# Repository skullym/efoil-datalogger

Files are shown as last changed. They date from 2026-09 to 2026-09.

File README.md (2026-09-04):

# efoil-datalogger
VESC based efoil data logger design by Mike Schulster
_____________________________________________________________________________________

DATA LOGGER DESIGN SPECS :
_________________________________________
Microcontroller : ESP32 Dev Module 38-pin

Storage : MicroSD module and 8GB card

GNSS : SAM-M10Q GNSS antenna module receiver from GNSS.store

Power : 5V from Vesc

________________________________
COMMS ARCHITECTURE :
_______________________________
Throttle : PPM from VESC  

VESC telemetry : UART 1 (COMM port)

GNSS : ESP32 UART 2

SD card : SPI

_______________________________
WIRING:
_______________________________
VESC UART1 TX  →  ESP32 GPIO16

VESC UART1 RX  ←  ESP32 GPIO17

GPS TX         →  ESP32 GPIO16  [use UART2]

GPS RX         ←  ESP32 GPIO17

SD CS/MOSI/MISO/CLK → GPIO 15/23/19/18

_______________________________________
OUTPUT FORMAT :
_______________________________________
Native VESC Tool CSV format

Exact header row from real VESC logs

One file per ride, named by GPS date/time

~5 Hz sample rate

___________________________________________
KEY LOGGED CHANNELS :
___________________________________________
VESC: voltage, motor current, input current, ERPM, duty cycle, watt-hours, FET temp, motor temp (via NTC) GPS: lat, lon, ground speed, altitude, time

___________________________________________________
RIDE DETECTION:
___________________________________________________
Auto-start: GPS speed >1 m/s or ERPM above threshold

Auto-stop: 30s idle timeout

Clean file close on stop

____________________________________________________
ANTENNA INSTALLATION :
____________________________________________________
Mounted flat, ceramic face up,

Small copper/aluminium ground plane underneath

15–20 cm minimum from ESC and battery cables if possible

Cable routed away from power wiring

_____________________________________________________________________
DATA LOGGER WIFI INTERFACE :
_____________________________________________________________________
SSID : eFoilLogger

Password : efoillogger

Can be changed in code lines 40 and 41

__________________________________________________________
FUNCTIONALITY :
__________________________________________________________
The logger has auto start-stop functionality built in - 

AUTO START : GNSS speed > 1.0 m/s for 3 seconds OR VESC data is recent AND abs(ERPM) > 300 for 3 seconds (can be changed on lines 63-64)

AUTO STOP :  no recent VESC data OR abs(ERPM) < 200 AND abs(input current) < 1.0 A OR GNSS speed < 0.7 m/s for at least 54 of the last 60 one-second samples (can be changed on lines 65-71) 

Also the logging can be MANUALLY started and stopped from the web interface.

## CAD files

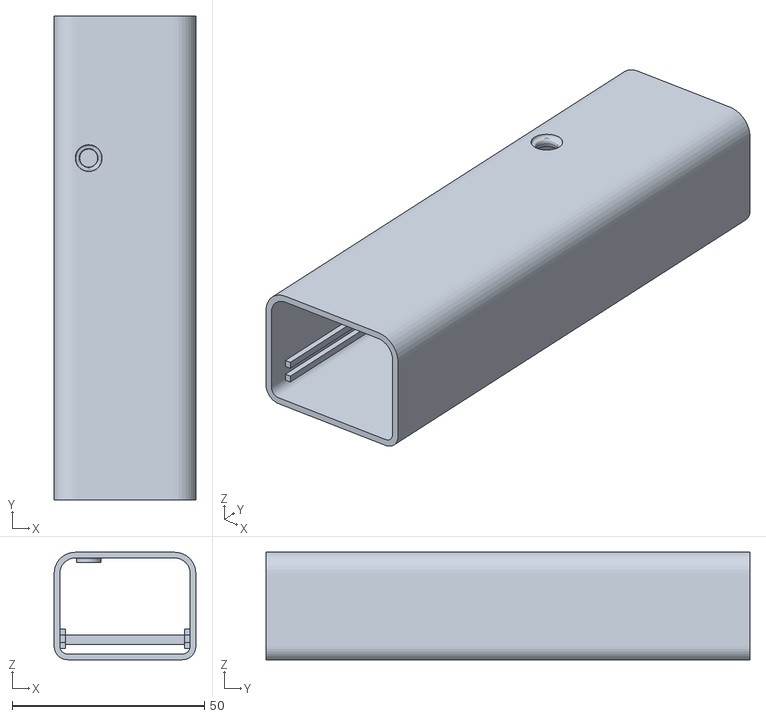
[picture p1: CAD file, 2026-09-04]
20260824 Data logger sleeve v2.0.stl
36.9 x 126.0 x 28.0

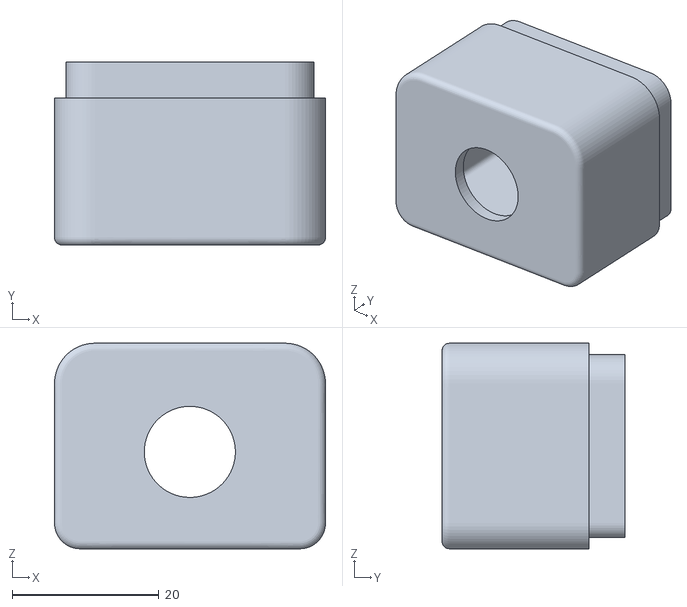
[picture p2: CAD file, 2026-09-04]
20260824 Cap hole V2.stl
36.9 x 24.9 x 28.0

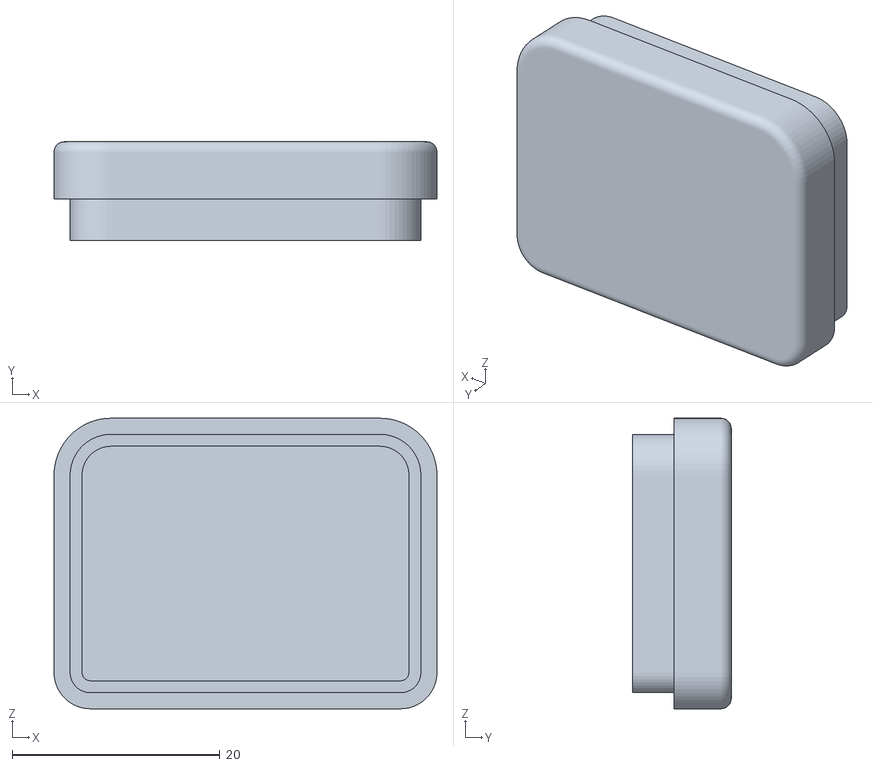
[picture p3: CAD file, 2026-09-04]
20260824 Cap blind V2.stl
36.9 x 9.50 x 28.0

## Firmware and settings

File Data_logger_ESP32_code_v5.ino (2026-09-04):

#include <TinyGPSPlus.h>
#include <SPI.h>
#include <SD.h>
#include <WiFi.h>
#include <WebServer.h>
#include <DNSServer.h>

// ELT0169 TX connects to GPIO25 (ESP32 RX).
// ELT0169 RX connects to GPIO26 (ESP32 TX).
constexpr int GPS_RX_PIN = 25;
constexpr int GPS_TX_PIN = 26;
constexpr uint32_t GPS_BAUD = 9600;

// VESC COMM UART.
// VESC TX connects to GPIO16 (ESP32 RX).
// VESC RX connects to GPIO17 (ESP32 TX).
constexpr int VESC_RX_PIN = 16;
constexpr int VESC_TX_PIN = 17;
constexpr uint32_t VESC_BAUD = 115200;
constexpr uint8_t COMM_GET_VALUES = 4;

// microSD module using the ESP32 VSPI pins.
constexpr int SD_CS_PIN = 5;
constexpr int SD_SCK_PIN = 18;
constexpr int SD_MISO_PIN = 19;
constexpr int SD_MOSI_PIN = 23;
constexpr uint32_t SD_SPI_FREQ = 1000000;
const char VESC_CSV_HEADER[] =
    "ms_today;input_voltage;temp_mos_max;temp_mos_1;temp_mos_2;temp_mos_3;"
    "temp_motor;current_motor;current_in;d_axis_current;q_axis_current;erpm;"
    "duty_cycle;amp_hours_used;amp_hours_charged;watt_hours_used;"
    "watt_hours_charged;tachometer;tachometer_abs;encoder_position;fault_code;"
    "vesc_id;d_axis_voltage;q_axis_voltage;ms_today_setup;amp_hours_setup;"
    "amp_hours_charged_setup;watt_hours_setup;watt_hours_charged_setup;"
    "battery_level;battery_wh_tot;current_in_setup;current_motor_setup;"
    "speed_meters_per_sec;tacho_meters;tacho_abs_meters;num_vescs;"
    "ms_today_imu;roll;pitch;yaw;accX;accY;accZ;gyroX;gyroY;gyroZ;"
    "gnss_posTime;gnss_lat;gnss_lon;gnss_alt;gnss_gVel;gnss_vVel;"
    "gnss_hAcc;gnss_vAcc;";
const char WIFI_SSID[] = "eFoilLogger";
const char WIFI_PASSWORD[] = "efoillogger";
constexpr byte DNS_PORT = 53;

// External status LED on GPIO27.
constexpr int LED_PIN = 27;
constexpr bool LED_ON = HIGH;
constexpr bool LED_OFF = LOW;

constexpr uint32_t REPORT_INTERVAL_MS = 1000;
constexpr bool SERIAL_LIVE_STATUS = false;
constexpr uint32_t SD_RETRY_INTERVAL_MS = 5000;
constexpr uint32_t VESC_POLL_INTERVAL_MS = 100;
constexpr uint32_t LOG_INTERVAL_MS = 200;
constexpr uint32_t LOG_FLUSH_INTERVAL_MS = 1000;
constexpr uint32_t LOG_CHECKPOINT_INTERVAL_MS = 30000;
constexpr bool LOG_FLUSH_EVERY_ROW = true;
constexpr uint32_t VESC_MAX_AGE_MS = 1000;
constexpr uint32_t FIX_MAX_AGE_MS = 2000;
constexpr uint32_t LED_GNSS_WAIT_BLINK_INTERVAL_MS = 250;
constexpr uint32_t LED_RECORD_PULSE_INTERVAL_MS = 2000;
constexpr uint32_t LED_RECORD_PULSE_OFF_MS = 120;
constexpr float START_SPEED_MPS = 1.0f;
constexpr float START_ERPM_ABS = 300.0f;
constexpr uint32_t START_CONFIRM_MS = 3000;
constexpr float STOP_SPEED_MPS = 0.7f;
constexpr float STOP_ERPM_ABS = 200.0f;
constexpr float STOP_INPUT_CURRENT_A = 1.0f;
constexpr uint32_t STOP_SPEED_SAMPLE_INTERVAL_MS = 1000;
constexpr uint8_t STOP_SPEED_WINDOW_SAMPLES = 60;
constexpr uint8_t STOP_SPEED_LOW_SAMPLES_REQUIRED = 54;
constexpr bool AUTO_STOP_ENABLED = true;
constexpr float DEFAULT_GNSS_HACC_M = 3.0f;
constexpr float DEFAULT_GNSS_VACC_M = 5.0f;
constexpr size_t MAX_WEB_FILES = 40;
constexpr uint8_t VESC_CSV_SEMICOLONS = 55;
constexpr uint8_t WEB_REFRESH_SECONDS = 5;
constexpr int32_t LOG_TIME_OFFSET_SECONDS = 2 * 3600;
constexpr uint32_t MS_PER_DAY = 86400000UL;

enum LoggerState {
  STATE_IDLE,
  STATE_RECORDING
};

TinyGPSPlus gps;
HardwareSerial gpsSerial(1);
HardwareSerial vescSerial(2);
WebServer *server = nullptr;
DNSServer dnsServer;

uint32_t lastReportMs = 0;
uint32_t lastSdRetryMs = 0;
uint32_t lastVescPollMs = 0;
uint32_t lastVescDataMs = 0;
uint32_t lastLogMs = 0;
uint32_t lastLogFlushMs = 0;
uint32_t lastLogCheckpointMs = 0;
uint32_t lastLedToggleMs = 0;
uint32_t logStartMillis = 0;
uint32_t logStartMsToday = 0;
uint32_t recordingStartedMillis = 0;
uint32_t lastRecordingDurationMs = 0;
uint32_t skippedBadRows = 0;
uint32_t loggedRows = 0;
uint32_t lastKnownLogSize = 0;
bool ledState = false;
bool sdReady = false;
bool logReady = false;
bool gnss5HzConfigured = false;
bool manualStartPending = false;
LoggerState loggerState = STATE_IDLE;
char logFileName[32] = "";
char lastStopReason[40] = "none";
File logFile;
uint32_t speedStartSinceMs = 0;
uint32_t erpmStartSinceMs = 0;
uint32_t lastStopSpeedSampleMs = 0;
uint8_t stopSpeedSampleIndex = 0;
uint8_t stopSpeedSampleCount = 0;
uint8_t stopSpeedLowSampleCount = 0;
bool stopSpeedLowSamples[STOP_SPEED_WINDOW_SAMPLES] = {false};
float vescTempMos = 0.0f;
float vescTempMotor = 0.0f;
float vescMotorCurrent = 0.0f;
float vescInputCurrent = 0.0f;
float vescDuty = 0.0f;
float vescRpm = 0.0f;
float vescVoltage = 0.0f;
float vescAmpHours = 0.0f;
float vescAmpHoursCharged = 0.0f;
float vescWattHours = 0.0f;
float vescWattHoursCharged = 0.0f;
int32_t vescTachometer = 0;
int32_t vescTachometerAbs = 0;
uint8_t vescFaultCode = 0;

void printTwoDigits(uint8_t value) {
  if (value < 10) {
    Serial.print('0');
  }
  Serial.print(value);
}

void printStatus() {
  const bool hasFix =
      gps.location.isValid() && gps.location.age() <= FIX_MAX_AGE_MS;

  Serial.print(F("GNSS fix="));
  Serial.print(hasFix ? F("YES") : F("NO"));

  Serial.print(F(", state="));
  Serial.print(loggerState == STATE_RECORDING ? F("RECORDING") : F("IDLE"));
  if (manualStartPending) {
    Serial.print(F("(manual start pending)"));
  }

  Serial.print(F(", sats="));
  if (gps.satellites.isValid()) {
    Serial.print(gps.satellites.value());
  } else {
    Serial.print(F("?"));
  }

  Serial.print(F(", hdop="));
  if (gps.hdop.isValid()) {
    Serial.print(gps.hdop.hdop(), 1);
  } else {
    Serial.print(F("?"));
  }

  Serial.print(F(", pos="));
  if (gps.location.isValid()) {
    Serial.print(gps.location.lat(), 7);
    Serial.print(F("/"));
    Serial.print(gps.location.lng(), 7);
  } else {
    Serial.print(F("waiting"));
  }

  Serial.print(F(", speed="));
  if (gps.speed.isValid()) {
    Serial.print(gps.speed.kmph(), 2);
    Serial.print(F("km/h"));
  } else {
    Serial.print(F("?"));
  }

  Serial.print(F(", local="));
  if (gps.date.isValid() && gps.time.isValid()) {
    uint16_t localYear;
    uint8_t localMonth;
    uint8_t localDay;
    uint8_t localHour;
    uint8_t localMinute;
    uint8_t localSecond;
    localGpsDateTime(localYear, localMonth, localDay,
                     localHour, localMinute, localSecond);

    Serial.print(localYear);
    Serial.print('-');
    printTwoDigits(localMonth);
    Serial.print('-');
    printTwoDigits(localDay);
    Serial.print(' ');
    printTwoDigits(localHour);
    Serial.print(':');
    printTwoDigits(localMinute);
    Serial.print(':');
    printTwoDigits(localSecond);
  } else {
    Serial.print(F("waiting"));
  }

  Serial.print(F(", nmea="));
  Serial.print(gps.charsProcessed());

  Serial.print(F(", VESC="));
  if (millis() - lastVescDataMs <= VESC_MAX_AGE_MS) {
    Serial.print(F("duty="));
    Serial.print(vescDuty * 100.0f, 1);
    Serial.print(F("% erpm="));
    Serial.print(vescRpm, 0);
    Serial.print(F(" motorA="));
    Serial.print(vescMotorCurrent, 1);
    Serial.print(F(" inputA="));
    Serial.print(vescInputCurrent, 1);
    Serial.print(F(" volts="));
    Serial.print(vescVoltage, 1);
  } else {
    Serial.print(F("waiting"));
  }

  Serial.print(F(", SD="));
  Serial.print(sdReady ? F("OK") : F("not ready"));

  Serial.print(F(", log="));
  if (logReady) {
    Serial.print(logFileName);
    Serial.print(F(", rows="));
    Serial.print(loggedRows);
    Serial.print(F(", size="));
    Serial.println(lastKnownLogSize);
  } else if (loggerState == STATE_IDLE && !manualStartPending) {
    Serial.println(F("not recording"));
  } else if (!sdReady) {
    Serial.println(F("waiting for SD"));
  } else if (!gpsDateTimeIsSane()) {
    Serial.println(F("waiting for valid GNSS date/time"));
  } else if (!gpsLocationIsUsable()) {
    Serial.println(F("waiting for usable GNSS position"));
  } else {
    Serial.println(F("ready"));
  }
}

uint16_t crc16(const uint8_t *data, uint16_t len) {
  uint16_t crc = 0;

  for (uint16_t i = 0; i < len; i++) {
    crc ^= static_cast<uint16_t>(data[i]) << 8;

    for (uint8_t bit = 0; bit < 8; bit++) {
      if (crc & 0x8000) {
        crc = (crc << 1) ^ 0x1021;
      } else {
        crc <<= 1;
      }
    }
  }

  return crc;
}

int16_t readInt16(const uint8_t *buffer, uint16_t &index) {
  uint16_t raw = (static_cast<uint16_t>(buffer[index]) << 8) |
                 static_cast<uint16_t>(buffer[index + 1]);
  index += 2;
  return static_cast<int16_t>(raw);
}

int32_t readInt32(const uint8_t *buffer, uint16_t &index) {
  uint32_t raw = (static_cast<uint32_t>(buffer[index]) << 24) |
                 (static_cast<uint32_t>(buffer[index + 1]) << 16) |
                 (static_cast<uint32_t>(buffer[index + 2]) << 8) |
                 static_cast<uint32_t>(buffer[index + 3]);
  index += 4;
  return static_cast<int32_t>(raw);
}

void sendVescGetValues() {
  const uint8_t payload[] = {COMM_GET_VALUES};
  const uint16_t crc = crc16(payload, sizeof(payload));

  vescSerial.write(2);
  vescSerial.write(sizeof(payload));
  vescSerial.write(payload, sizeof(payload));
  vescSerial.write(static_cast<uint8_t>(crc >> 8));
  vescSerial.write(static_cast<uint8_t>(crc & 0xFF));
  vescSerial.write(3);
}

void parseVescPayload(const uint8_t *payload, uint16_t len) {
  if (len < 1 || payload[0] != COMM_GET_VALUES) {
    return;
  }

  // COMM_GET_VALUES response layout starts with temperatures/currents, then
  // duty cycle and ERPM. Skip fields we are not showing in this test sketch.
  uint16_t index = 1;
  if (len < 55) {
    return;
  }

  vescTempMos = readInt16(payload, index) / 10.0f;
  vescTempMotor = readInt16(payload, index) / 10.0f;
  vescMotorCurrent = readInt32(payload, index) / 100.0f;
  vescInputCurrent = readInt32(payload, index) / 100.0f;
  readInt32(payload, index);                 // id current / 100
  readInt32(payload, index);                 // iq current / 100
  vescDuty = readInt16(payload, index) / 1000.0f;
  vescRpm = readInt32(payload, index);
  vescVoltage = readInt16(payload, index) / 10.0f;
  vescAmpHours = readInt32(payload, index) / 10000.0f;
  vescAmpHoursCharged = readInt32(payload, index) / 10000.0f;
  vescWattHours = readInt32(payload, index) / 10000.0f;
  vescWattHoursCharged = readInt32(payload, index) / 10000.0f;
  vescTachometer = readInt32(payload, index);
  vescTachometerAbs = readInt32(payload, index);
  vescFaultCode = payload[index];
  lastVescDataMs = millis();
}

void pollVesc(uint32_t now) {
  if (now - lastVescPollMs < VESC_POLL_INTERVAL_MS) {
    return;
  }

  lastVescPollMs = now;
  sendVescGetValues();
}

void readVesc() {
  static uint8_t packet[256];
  static uint16_t index = 0;
  static uint16_t payloadLen = 0;
  static uint8_t crcHigh = 0;
  static uint8_t crcLow = 0;
  static uint8_t state = 0;

  while (vescSerial.available() > 0) {
    const uint8_t value = vescSerial.read();

    switch (state) {
      case 0:
        if (value == 2) {
          state = 1;
          index = 0;
          payloadLen = 0;
        }
        break;

      case 1:
        payloadLen = value;
        if (payloadLen == 0 || payloadLen > sizeof(packet)) {
          state = 0;
        } else {
          state = 2;
        }
        break;

      case 2:
        packet[index++] = value;
        if (index >= payloadLen) {
          state = 3;
        }
        break;

      case 3: {
        crcHigh = value;
        state = 4;
        break;
      }

      case 4:
        crcLow = value;
        state = 5;
        break;

      case 5: {
        const uint8_t endByte = value;
        const uint16_t receivedCrc =
            (static_cast<uint16_t>(crcHigh) << 8) | crcLow;

        if (endByte == 3 && receivedCrc == crc16(packet, payloadLen)) {
          parseVescPayload(packet, payloadLen);
        }

        state = 0;
        break;
      }
    }
  }
}

void testSdCard() {
  Serial.println();
  Serial.println(F("--- SD card test ---"));
  Serial.println(F("Pins: CS=5, SCK=18, MISO=19, MOSI=23"));

  SPI.begin(SD_SCK_PIN, SD_MISO_PIN, SD_MOSI_PIN, SD_CS_PIN);

  if (!SD.begin(SD_CS_PIN, SPI, SD_SPI_FREQ)) {
    Serial.println(F("SD init failed. Check wiring, power, card format and CS pin."));
    sdReady = false;
    return;
  }

  sdReady = true;
  Serial.println(F("SD init OK"));

  uint64_t cardSizeMb = SD.cardSize() / (1024ULL * 1024ULL);
  Serial.print(F("Card size: "));
  Serial.print(cardSizeMb);
  Serial.println(F(" MB"));
  Serial.println(F("--- SD init done ---"));
}

bool ensureSdReady(bool verbose = false) {
  for (uint8_t attempt = 1; attempt <= 5; attempt++) {
    File root = SD.open("/");
    if (root) {
      root.close();
      sdReady = true;
      return true;
    }

    delay(100);
  }

  if (verbose) {
    Serial.println(F("SD root not available."));
    Serial.println(F("Trying automatic SD remount..."));
  }

  SD.end();
  delay(300);
  SPI.begin(SD_SCK_PIN, SD_MISO_PIN, SD_MOSI_PIN, SD_CS_PIN);
  sdReady = SD.begin(SD_CS_PIN, SPI, SD_SPI_FREQ);

  if (sdReady) {
    File root = SD.open("/");
    if (root) {
      root.close();
      if (verbose) {
        Serial.println(F("Automatic SD remount OK"));
      }
      return true;
    }
  }

  sdReady = false;
  if (verbose) {
    Serial.println(F("Automatic SD remount failed."));
  }
  return false;
}

bool remountSd(bool verbose = false) {
  if (verbose) {
    Serial.println(F("Manual SD remount..."));
  }

  SD.end();
  delay(300);
  SPI.begin(SD_SCK_PIN, SD_MISO_PIN, SD_MOSI_PIN, SD_CS_PIN);
  sdReady = SD.begin(SD_CS_PIN, SPI, SD_SPI_FREQ);

  if (sdReady) {
    File root = SD.open("/");
    if (root) {
      root.close();
    } else {
      sdReady = false;
    }
  }

  if (verbose) {
    Serial.println(sdReady ? F("Manual SD remount OK") : F("Manual SD remount failed"));
  }

  return sdReady;
}

uint32_t gpsMsToday() {
  if (!gps.time.isValid()) {
    return millis();
  }

  return static_cast<uint32_t>(gps.time.hour()) * 3600000UL +
         static_cast<uint32_t>(gps.time.minute()) * 60000UL +
         static_cast<uint32_t>(gps.time.second()) * 1000UL +
         static_cast<uint32_t>(gps.time.centisecond()) * 10UL;
}

bool isLeapYear(uint16_t year) {
  return (year % 4 == 0 && year % 100 != 0) || (year % 400 == 0);
}

uint8_t daysInMonth(uint16_t year, uint8_t month) {
  static const uint8_t days[] = {31, 28, 31, 30, 31, 30,
                                 31, 31, 30, 31, 30, 31};
  if (month == 2 && isLeapYear(year)) {
    return 29;
  }

  if (month < 1 || month > 12) {
    return 31;
  }

  return days[month - 1];
}

void incrementDate(uint16_t &year, uint8_t &month, uint8_t &day) {
  day++;
  if (day <= daysInMonth(year, month)) {
    return;
  }

  day = 1;
  month++;
  if (month <= 12) {
    return;
  }

  month = 1;
  year++;
}

void localGpsDateTime(uint16_t &year, uint8_t &month, uint8_t &day,
                      uint8_t &hour, uint8_t &minute, uint8_t &second) {
  year = gps.date.year();
  month = gps.date.month();
  day = gps.date.day();

  int32_t localSeconds =
      static_cast<int32_t>(gps.time.hour()) * 3600L +
      static_cast<int32_t>(gps.time.minute()) * 60L +
      static_cast<int32_t>(gps.time.second()) +
      LOG_TIME_OFFSET_SECONDS;

  while (localSeconds >= 86400L) {
    localSeconds -= 86400L;
    incrementDate(year, month, day);
  }

  hour = localSeconds / 3600L;
  minute = (localSeconds % 3600L) / 60L;
  second = localSeconds % 60L;
}

uint32_t gpsLocalMsToday() {
  if (!gps.time.isValid()) {
    return millis();
  }

  return (gpsMsToday() +
          static_cast<uint32_t>(LOG_TIME_OFFSET_SECONDS) * 1000UL) %
         MS_PER_DAY;
}

bool gpsDateTimeIsSane() {
  return gps.date.isValid() && gps.time.isValid() &&
         gps.date.year() >= 2024 &&
         gps.date.month() >= 1 && gps.date.month() <= 12 &&
         gps.date.day() >= 1 && gps.date.day() <= 31;
}

bool gpsLocationIsUsable() {
  return gps.location.isValid() && gps.location.age() <= FIX_MAX_AGE_MS &&
         (gps.location.lat() != 0.0 || gps.location.lng() != 0.0);
}

bool recordingPrerequisitesReady() {
  return sdReady && gpsDateTimeIsSane() && gpsLocationIsUsable();
}

float currentGnssSpeedMps() {
  if (!gps.speed.isValid() || gps.speed.age() > FIX_MAX_AGE_MS) {
    return 0.0f;
  }

  return gps.speed.mps();
}

bool vescDataIsRecent(uint32_t now) {
  return now - lastVescDataMs <= VESC_MAX_AGE_MS;
}

uint32_t logMsToday(uint32_t now) {
  if (!logReady) {
    return gpsLocalMsToday();
  }

  return (logStartMsToday + (now - logStartMillis)) % MS_PER_DAY;
}

void sendUbx(uint8_t messageClass, uint8_t messageId, const uint8_t *payload,
             uint16_t payloadLen) {
  uint8_t ckA = 0;
  uint8_t ckB = 0;

  auto updateChecksum = [&ckA, &ckB](uint8_t value) {
    ckA = ckA + value;
    ckB = ckB + ckA;
  };

  gpsSerial.write(0xB5);
  gpsSerial.write(0x62);

  gpsSerial.write(messageClass);
  updateChecksum(messageClass);

  gpsSerial.write(messageId);
  updateChecksum(messageId);

  const uint8_t lenLow = payloadLen & 0xFF;
  const uint8_t lenHigh = payloadLen >> 8;
  gpsSerial.write(lenLow);
  updateChecksum(lenLow);
  gpsSerial.write(lenHigh);
  updateChecksum(lenHigh);

  for (uint16_t i = 0; i < payloadLen; i++) {
    gpsSerial.write(payload[i]);
    updateChecksum(payload[i]);
  }

  gpsSerial.write(ckA);
  gpsSerial.write(ckB);
}

void configureGnss5Hz() {
  // UBX-CFG-RATE: measRate=200 ms, navRate=1, timeRef=UTC.
  const uint8_t payload[] = {
      0xC8, 0x00,
      0x01, 0x00,
      0x00, 0x00,
  };

  sendUbx(0x06, 0x08, payload, sizeof(payload));
  Serial.println(F("Requested GNSS update rate: 5 Hz"));
}

void printCsvValue(File &file, float value, uint8_t decimals) {
  file.print(value, decimals);
  file.print(';');
}

void printCsvValue(File &file, int32_t value) {
  file.print(value);
  file.print(';');
}

void printCsvValue(File &file, int value) {
  file.print(value);
  file.print(';');
}

void printCsvValue(File &file, uint32_t value) {
  file.print(value);
  file.print(';');
}

void printCsvValue(File &file, uint8_t value) {
  file.print(value);
  file.print(';');
}

void printCsvValue(String &row, float value, uint8_t decimals) {
  row += String(value, static_cast<unsigned int>(decimals));
  row += ';';
}

void printCsvValue(String &row, int32_t value) {
  row += String(value);
  row += ';';
}

void printCsvValue(String &row, int value) {
  row += String(value);
  row += ';';
}

void printCsvValue(String &row, uint32_t value) {
  row += String(value);
  row += ';';
}

void printCsvValue(String &row, uint8_t value) {
  row += String(value);
  row += ';';
}

void appendToRow(char *row, size_t rowSize, size_t &pos, const char *format, ...) {
  if (pos >= rowSize) {
    return;
  }

  va_list args;
  va_start(args, format);
  int written = vsnprintf(row + pos, rowSize - pos, format, args);
  va_end(args);

  if (written > 0) {
    pos += static_cast<size_t>(written);
    if (pos >= rowSize) {
      pos = rowSize - 1;
    }
  }
}

uint8_t countSemicolons(const char *row) {
  uint8_t count = 0;
  while (*row != '\0') {
    if (*row == ';') {
      count++;
    }
    row++;
  }
  return count;
}

bool openLogFile() {
  if (logReady) {
    return true;
  }

  if (!recordingPrerequisitesReady()) {
    return false;
  }

  uint16_t localYear;
  uint8_t localMonth;
  uint8_t localDay;
  uint8_t localHour;
  uint8_t localMinute;
  uint8_t localSecond;
  localGpsDateTime(localYear, localMonth, localDay,
                   localHour, localMinute, localSecond);

  snprintf(logFileName, sizeof(logFileName), "/%04u-%02u-%02u_%02u-%02u-%02u.csv",
           static_cast<unsigned int>(localYear),
           static_cast<unsigned int>(localMonth),
           static_cast<unsigned int>(localDay),
           static_cast<unsigned int>(localHour),
           static_cast<unsigned int>(localMinute),
           static_cast<unsigned int>(localSecond));

  const bool fileAlreadyExists = SD.exists(logFileName);
  logFile = SD.open(logFileName, FILE_APPEND);
  if (!logFile) {
    Serial.println(F("Could not create VESC CSV log file."));
    return false;
  }

  if (!fileAlreadyExists) {
    logFile.println(VESC_CSV_HEADER);
    logFile.flush();
  }

  logReady = true;
  logStartMillis = millis();
  logStartMsToday = gpsLocalMsToday();
  lastLogFlushMs = millis();
  lastLogCheckpointMs = millis();
  loggedRows = 0;
  lastKnownLogSize = logFile.size();

  Serial.print(F("VESC CSV log: "));
  Serial.println(logFileName);

  return true;
}

bool startRecording(const char *reason) {
  if (loggerState == STATE_RECORDING) {
    return true;
  }

  if (!openLogFile()) {
    return false;
  }

  loggerState = STATE_RECORDING;
  manualStartPending = false;
  speedStartSinceMs = 0;
  erpmStartSinceMs = 0;
  recordingStartedMillis = millis();
  resetStopSpeedWindow(recordingStartedMillis);

  Serial.print(F("Recording started: "));
  Serial.println(reason);
  return true;
}
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
void loop() {
  while (gpsSerial.available() > 0) {
    gps.encode(gpsSerial.read());
  }

  const uint32_t now = millis();
  handleWeb();
  handleSerialCommands();
  readVesc();
  pollVesc(now);
  updateFixLed(now);
  configureGnss5HzIfReady();
  updateRecordingState(now);
  writeVescCsvRow(now);
  handleWeb();

  if (!sdReady && now - lastSdRetryMs >= SD_RETRY_INTERVAL_MS) {
    lastSdRetryMs = now;
    ensureSdReady(true);
  }

  if (SERIAL_LIVE_STATUS && now - lastReportMs >= REPORT_INTERVAL_MS) {
    lastReportMs = now;
    printStatus();

    if (now > 5000 && gps.charsProcessed() == 0) {
      Serial.println(F("WARNING: No GNSS data received. Check power, wiring and baud."));
    }
  }
}
